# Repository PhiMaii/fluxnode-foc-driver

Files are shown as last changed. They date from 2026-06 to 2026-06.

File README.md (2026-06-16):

# FluxNode-FOC

FluxNode-FOC is a compact, general-purpose BLDC motor controller designed for field-oriented control in robotics, actuators, experimental drives, and motor-integrated applications.

The project combines a high-performance STM32G4 microcontroller, a three-phase MOSFET power stage, three-phase current sensing, rotor position sensing, phase-voltage measurement, CAN-FD communication, USB, temperature monitoring, and an optional brake chopper.

The design is intended to be understandable, repairable, and extensible rather than optimized only for minimum cost or minimum PCB area.

> **Project status:** Hardware and firmware architecture are still under development. Electrical values, component selections, interfaces, and PCB details may change before the first validated hardware revision.

---

## 1. Main design targets

| Parameter | Target |
|---|---:|
| Battery voltage | Up to 8S Li-ion/LiPo |
| Maximum normal battery voltage | 33.6 V |
| Design measurement range | Up to approximately 40 V |
| Nominal development voltage | 24 V |
| Continuous phase current target | Approximately 8 A RMS |
| Peak current target | Approximately 20 A |
| PWM frequency | 25 kHz |
| Control method | Field-oriented control |
| Power MOSFET voltage rating | 60 V |
| Bulk capacitor voltage rating | 50–63 V |
| Main communication interface | CAN-FD |
| MCU | STM32G474RE |
| Gate driver | DRV8323SRTAR |
| Main rotor encoder | AS5047P |
| PCB stackup | 6 layers preferred |

The controller is designed around **8S operation**, not 10S. A fully charged 8S battery reaches 33.6 V. Additional margin is required for wiring inductance, regenerative braking, switching transients, and load-disconnect events.

The system may be operated from lower voltages, including a 24 V laboratory supply, as long as the supply is compatible with regenerative energy or appropriate braking and overvoltage protection are provided.

---

## 2. Design philosophy

The main design priorities are:

1. Reliable and accurately timed current measurement for FOC.
2. Low-inductance power-stage layout.
3. Sufficient voltage margin for an 8S battery system.
4. Good observability through current, voltage, temperature, and diagnostic measurements.
5. Expandability for different motors, sensors, and actuator configurations.
6. Firmware that is understandable and not tightly coupled to a single framework.
7. Practical assembly and debugging with commonly available tools.

The design intentionally includes features that are not strictly required for basic FOC, such as phase-voltage sensing, several temperature channels, CAN-FD, an auxiliary sensor interface, and an optional brake chopper. These features make the controller more useful as a development platform and provide additional diagnostic and protection options.

---

## 3. System architecture

The controller is divided into the following main functional blocks:

- Power input and protection
- Auxiliary power supplies
- STM32G474 control section
- DRV8323 gate driver
- Three-phase MOSFET bridge
- Three-phase current measurement
- Phase-voltage and DC-bus voltage measurement
- Rotor-position sensing
- Temperature monitoring
- CAN-FD and USB communication
- Optional external sensor interfaces
- Optional brake chopper
- Fan and debug outputs

The KiCad schematic should remain split into logical hierarchical sheets rather than placing the entire design on one sheet.

Suggested schematic sheets:

```text
Power Input
Power Supplies
MCU Core
Gate Driver
Power Stage
Current Sense
Voltage Sense
Encoders and Sensors
CAN and USB
Temperature and Fan
Brake Chopper
Debug and Expansion
```

---

## 4. Microcontroller

The selected MCU is the **STM32G474RE**, based on the STM32G4 family.

Reasons for selecting this MCU include:

- High-performance Cortex-M4 core
- Floating-point unit
- Advanced motor-control timers
- Multiple fast ADCs
- Internal operational amplifiers and comparators
- CORDIC and FMAC accelerators
- Multiple SPI peripherals
- FDCAN support
- USB device support
- DAC outputs
- Good support through STM32CubeMX and STM32Cube firmware packages

The STM32G474xB/xC/xE datasheet is the reference MCU datasheet for this project.

### Motor-control timer

TIM1 is reserved for the three-phase complementary PWM outputs.

The current pin allocation uses:

- TIM1 channel 2 and channel 2N
- TIM1 channel 3 and channel 3N
- TIM1 channel 4 and channel 4N

TIM1 channel 4 on the selected STM32G474 package has a complementary output and can therefore be used as one of the three half-bridge PWM channels.

TIM1 should be configured for:

- Center-aligned PWM
- Complementary outputs
- Programmable dead time
- Break input support
- 25 kHz switching frequency
- ADC trigger generation at defined points in the PWM cycle

The exact output polarity and idle states must match the DRV8323 input configuration.

---

## 5. Gate driver

The selected gate driver is the **DRV8323SRTAR**.

It provides:

- Three half-bridge gate-drive channels
- SPI configuration and diagnostics
- Adjustable gate-drive strength
- Current-shunt amplifier support
- Fault reporting
- Undervoltage and overcurrent protection features

The gate driver is connected to the STM32 through:

- Six PWM signals
- SPI clock, COPI, CIPO, and chip select
- Enable signal
- nFAULT signal
- Optional additional diagnostic signals
- Analog VREF generated by an MCU DAC

### Gate-driver SPI

The gate driver shares SPI1 with the onboard magnetic encoder. Each device has a separate chip-select signal and is accessed sequentially.

This sharing is acceptable because neither device requires continuous full-bandwidth SPI traffic. Motor-control timing must not depend on slow or blocking SPI transactions.

The external auxiliary SPI connector uses SPI3 so that optional external hardware does not disturb the main gate-driver and encoder bus.

### nFAULT

The gate-driver fault output should be connected to an interrupt-capable GPIO input.

Software should log and decode the driver fault registers, but hardware protection must not rely only on software response time. Where practical, the timer break input should be used for immediate PWM shutdown.

### VREF

The DRV8323 current-sense amplifier reference is generated by a DAC output from the STM32 rather than being permanently tied to 3.3 V.

This allows the current-sense zero point to be adjusted in firmware. The DAC output must be properly decoupled and kept quiet because noise on VREF directly affects all current measurements.

---

## 6. Power stage

The three-phase inverter uses six external N-channel MOSFETs.

The currently selected phase MOSFET is:

- **TPW1R306PL**

The design uses 60 V MOSFETs to provide useful margin above the 33.6 V maximum battery voltage. This margin is still not sufficient by itself to tolerate uncontrolled regenerative voltage rise or poor PCB layout, so transient suppression and bus-voltage monitoring remain necessary.

### Power-stage layout priorities

The following loops must be kept as small as possible:

- High-side MOSFET, low-side MOSFET, and local ceramic/bulk capacitor commutation loop
- Gate-driver source and sink loops
- Bootstrap capacitor loops
- Current-shunt measurement loops

The gate driver and gate resistors must be placed close to the MOSFETs. Gate traces should be short, direct, and separated from high-current switching nodes.

Kelvin source connections should be used where practical for gate-drive return and current measurement.

The phase nodes are high-dV/dt switching nodes and should have limited copper area. They should not run beneath sensitive analog circuits, the encoder, the crystal, USB, or communication interfaces.

---

## 7. Power input and voltage protection

The input stage is designed for an 8S battery or a suitable DC supply.

Required or planned protection includes:

- Reverse-polarity protection where practical
- Input fuse or external fused supply
- TVS diode or equivalent transient suppression
- Local ceramic decoupling close to the bridge
- 50–63 V rated bulk capacitors
- DC-bus voltage measurement
- Firmware overvoltage and undervoltage limits
- Optional brake chopper
- Consideration of regenerative current into the source

The exact TVS voltage must be selected together with the maximum allowed bus voltage, MOSFET rating, gate-driver rating, and expected transient energy. It must not clamp during normal 8S operation but must act before the power stage is exposed to unsafe voltage.

A bench supply may not be able to absorb regenerative current. Motor deceleration can therefore raise the bus voltage even when the controller is powered from a regulated supply.

---

## 8. Current sensing

The design measures all three phase currents.

Each phase has its own shunt measurement path, allowing:

- Three-phase current reconstruction
- More flexible sampling
- Better diagnostics
- Detection of measurement inconsistencies
- Improved operation in modulation regions where two-shunt measurement becomes difficult

The phase-current channels are distributed across separate ADCs where possible so that they can be sampled simultaneously or with minimal timing skew.

The current measurements are configured as injected ADC conversions triggered by TIM1. Sampling should occur at a defined low-noise point in the PWM cycle.

Important requirements:

- Use differential/Kelvin routing from each shunt.
- Keep current-sense traces away from phase nodes and gate traces.
- Place input filtering near the receiving amplifier or ADC input as appropriate.
- Keep the three channels electrically symmetrical.
- Calibrate current offsets before enabling the power stage.
- Recheck offsets when temperature or VREF changes significantly.
- Detect ADC saturation and implausible current combinations.

Phase-current ADCs should remain the highest-priority analog measurements. Slower signals such as temperature and battery voltage should use regular conversions or lower-priority ADC resources.

---

## 9. Phase-voltage sensing

All three motor phases are measured through resistor dividers.

Phase-voltage sensing is not required for basic encoder-based FOC, but it provides several useful capabilities:

- Back-EMF observation
- Sensorless experimentation
- Motor-state diagnostics
- Phase-disconnection detection
- Verification of switching behavior
- Improved startup and fault analysis
- Potential observer development

The chosen divider concept uses two series high-side resistors and one low-side resistor to distribute voltage stress and improve routing.

The currently considered common value set is:

```text
High side: 2 × 51 kΩ
Low side: 6.8 kΩ
```

This ratio provides margin for phase and bus voltage excursions near 40 V while keeping the ADC voltage within the 3.3 V domain.

The final divider values must be verified against:

- ADC absolute maximum voltage
- Resistor tolerance
- Maximum expected transient voltage
- ADC input leakage
- Sampling-time requirements
- Desired measurement bandwidth

A small capacitor at the ADC-side divider node provides anti-aliasing and switching-noise filtering. A value around **1 nF** is currently considered for the phase-voltage channels, subject to final simulation and measurement.

The divider resistors should be placed close to the phase-sense pickup, while the final filter capacitor and any small series protection resistor should be placed close to the MCU ADC input. Routing between the divider and MCU must avoid switching nodes.

The phase voltages should be sampled from a timer-derived trigger at a repeatable point in the PWM cycle. They do not necessarily need the same timing priority as the phase currents.

---

## 10. DC-bus voltage sensing

The battery/DC-bus voltage is measured by an external resistor divider connected to an ADC channel.

The MCU VBAT pin is not used for measuring the motor supply. The external motor bus can reach approximately 40 V during transients and requires a dedicated divider.

The bus-voltage channel is used for:

- Undervoltage protection
- Overvoltage protection
- Brake-chopper control
- Regenerative-braking management
- Power and energy estimation
- Supply diagnostics

The same general divider ratio as the phase-voltage measurement may be used to simplify the bill of materials:

```text
High side: 2 × 51 kΩ
Low side: 6.8 kΩ
```

The bus voltage changes much more slowly than the phase-node voltage, so it should use stronger filtering than the phase-voltage channels. The final capacitor value should be chosen based on the desired brake-chopper response and ADC sampling rate.

The divider must be connected directly to the actual power-stage DC bus rather than to a remote or lightly loaded supply node.

---

## 11. Rotor-position sensing

The main onboard rotor encoder is the **AS5047P**.

It is connected by SPI and is intended to provide the rotor angle used by the FOC algorithm.

Reasons for choosing the AS5047P include:

- 14-bit absolute angle output
- High-speed SPI interface
- Suitability for motor-control applications
- On-chip dynamic angle error compensation
- Diagnostic information
- Common use in compact BLDC actuators

The encoder shares SPI1 with the DRV8323, using a separate chip-select signal.

Encoder transactions should be:

- Short
- Deterministic
- Checked for communication and parity errors
- Scheduled so they do not interfere with the current-control interrupt

DMA may be added later if it measurably improves timing or CPU load, but it is not required for initial firmware bring-up.

The PCB must respect the encoder manufacturer's magnet alignment, air-gap, magnetic-field, and keepout recommendations.

An additional external sensor interface is available through SPI3. This may be used for:

- A second encoder
- An off-axis sensor
- An external actuator sensor
- Experimental sensors

The external sensor is optional and not required for initial operation.

---

## 12. ADC allocation philosophy

The STM32G474 provides multiple ADCs, which are used to separate timing-critical and slow measurements.

The allocation philosophy is:

- Distribute the three phase-current measurements across ADC1, ADC2, and ADC3 where possible.
- Use injected conversions triggered by TIM1 for phase currents.
- Place phase-voltage measurements on available ADC channels, even when one ADC must contain two phase-voltage channels.
- Use regular conversions for bus voltage and temperature measurements.
- Use ADC4 and ADC5 for lower-priority auxiliary measurements where convenient.
- Avoid sacrificing correct phase-current timing merely to make the ADC channel allocation look symmetrical.

Current and phase-voltage measurements may share an ADC if the injected and regular sequences are configured carefully. The timing-critical current conversion always has priority.

---

## 13. Temperature monitoring

Planned temperature measurements include:

- Power MOSFET temperature
- Motor temperature
- Brake-chopper resistor or chopper-stage temperature
- MCU internal temperature

External temperatures are measured with NTC resistor dividers connected to ADC inputs.

Temperature monitoring is used for:

- Warning thresholds
- Current derating
- Fan control
- Controlled shutdown
- Fault logging

The MCU internal temperature sensor can be sampled in addition to the external channels. It is useful for board-level thermal monitoring but does not replace a sensor close to the MOSFETs.

NTC channels are slow signals and do not require timer-synchronous sampling.

---

## 14. Brake chopper

An optional brake chopper is included to prevent excessive DC-bus voltage during regenerative braking.

The brake chopper consists of:

- A power MOSFET
- Gate-drive circuitry
- An external or onboard braking resistor connection
- Bus-voltage feedback
- Temperature monitoring where practical
- Firmware control and fault limits

The braking resistor may be implemented as an external add-on connected through a dedicated power connector. This avoids placing a large, hot resistor on the compact controller PCB.

The chopper is controlled from a timer PWM output. It is currently assigned separately from the fan PWM so that both functions can operate independently.

The chopper is activated based on the measured DC-bus voltage. Typical firmware behavior will include:

1. Chopper remains off below the activation threshold.
2. PWM duty increases when the bus exceeds the target voltage.
3. Duty is reduced as the bus voltage falls.
4. A higher emergency threshold disables motor PWM if the chopper cannot control the bus.
5. Temperature and maximum duty limits protect the MOSFET and resistor.

The exact voltage thresholds depend on the final TVS selection, capacitor rating, MOSFET margin, and maximum permitted bus voltage.

The brake chopper must default to off during reset and startup.

---

## 15. Communication interfaces

### CAN-FD

CAN-FD is the main external real-time communication interface.

It is intended for:

- Commands and setpoints
- Telemetry
- Fault reporting
- Parameter configuration
- Multi-axis systems
- Daisy-chain-style wiring between actuator nodes

Electrical CAN wiring is a bus, not a logical point-to-point daisy chain. Connectors may provide CAN in and CAN out for convenient physical chaining, but all nodes share the same differential bus.

The controller should include:

- CAN transceiver
- CANH and CANL routing as a differential pair
- Optional switchable termination
- ESD protection near the connector
- Ground reference
- Suitable connector pinout for repeated nodes

Termination should only be enabled at the two physical ends of the CAN bus.

### USB-C

USB-C provides a local interface for:

- Firmware development
- Configuration
- Diagnostics
- Bootloader or device firmware update
- High-rate local telemetry where useful

USB is not intended to power the motor stage.

The USB section includes:

- USB 2.0 full-speed D+ and D−
- 22 Ω series resistors close to the MCU
- ESD protection close to the connector
- Correct USB-C CC resistors for a device
- VBUS sensing
- Protection against unwanted back-powering when USB and the motor battery are connected simultaneously

USB 5 V and the board's main supply must not be directly tied together without a deliberate power-path design.

---

## 16. Auxiliary interfaces

The board includes optional external interfaces for future sensors and accessories.

Planned interfaces include:

- SPI3 auxiliary sensor port
- I2C sensor port
- Fan connector
- External brake-resistor connector
- SWD debugging connector
- Debug LEDs
- Optional spare GPIO or timer signals where routing permits

The external SPI port is separate from the main SPI1 bus. This prevents an optional cable-connected device from adding excessive capacitance or noise to the gate-driver and onboard-encoder interface.

I2C is intended for relatively slow optional sensors. Pull-up resistors should be configurable or removable so that multiple boards or sensor modules do not unintentionally place too many pull-ups in parallel.

---

## 17. Fan control

An external fan can be controlled through a timer PWM output.

The fan output is independent of the brake-chopper PWM.

Firmware may control fan speed based on:

- MOSFET temperature
- Motor current
- Board temperature
- Brake-chopper activity
- User configuration

The MCU pin must not directly drive a fan motor. A suitable transistor or MOSFET stage, flyback protection where required, and connector decoupling must be provided.

---

## 18. Debugging and programming

The primary programming and debugging interface is SWD.

Required signals include:

- SWDIO
- SWCLK
- NRST
- GND
- Target reference voltage
- Optional SWO

SWO should be routed if pin availability allows it, because it can provide low-overhead debug output and timing information.

Boot configuration and reset access should remain available during bring-up.

At least two debug LEDs are planned for basic status and fault indication.

---

## 19. PCB stackup and layout

A **6-layer PCB** is preferred.

Although a 4-layer design is technically possible, the small additional fabrication cost of six layers is justified by the complexity of the mixed-signal motor-control board.

A possible six-layer stackup is:

```text
L1: Components, short signals, power-stage copper
L2: Solid ground plane
L3: Power distribution
L4: Secondary power and slower signals
L5: Solid ground plane
L6: Signals and low-current components
```

The exact stackup must be selected from the PCB manufacturer's controlled stackup options.

### Reasons for using six layers

- Better uninterrupted ground references
- Easier separation of power and sensitive analog routing
- Improved return-current paths
- More practical routing around the LQFP MCU
- Better EMI performance
- Easier CAN, USB, SPI, and ADC routing
- Reduced need to split or perforate the main ground plane

### Ground strategy

The design should use a continuous ground system rather than creating isolated analog and digital ground islands.

Sensitive analog circuits should be separated by placement and return-current control, not by cutting the ground plane.

High-current power returns must not share narrow copper paths with:

- ADC reference returns
- Current-sense returns
- Encoder ground
- USB ground
- MCU decoupling returns

Use stitching vias around noisy power areas, board edges where appropriate, and layer transitions.

### Placement order

Recommended placement order:

1. MOSFET bridge and power connectors
2. DC-link capacitors
3. Gate driver and gate components
4. Current shunts and sense paths
5. MCU and decoupling
6. Encoder
7. Power supplies
8. CAN and USB
9. Auxiliary connectors
10. Debug and low-priority circuitry

The power-stage layout should be completed before general digital routing.

---

## 20. Component sizes and assembly

The board uses a mixture of 0402 and 0603 passives.

General preference:

- Use 0402 where density or very low parasitic inductance matters.
- Use 0603 for resistor dividers, manually reworked parts, and components exposed to higher voltage.
- Use appropriately larger packages for high-power, high-voltage, or high-capacitance components.
- Do not select 0402 only to reduce board area if it makes probing and rework unnecessarily difficult.

For voltage dividers connected to the motor bus or phase nodes, 0603 resistors are preferred. Splitting the high-side resistance between two components reduces the voltage across each resistor and improves layout flexibility.

The PCB is intended to be assembled with solder paste, hot plate or reflow, hot air, flux, and hand rework where necessary. 0402 assembly is possible but requires careful paste control and inspection.

---

## 21. Firmware workflow

The firmware is generated initially with **STM32CubeMX** and developed in **Visual Studio Code**.

PlatformIO is not used for this project.

The intended workflow is:

1. Configure pins, clocks, ADCs, timers, DMA, communication peripherals, and middleware in STM32CubeMX.
2. Generate the STM32 project and initialization code.
3. Open and develop the generated project in Visual Studio Code.
4. Keep application code outside generated sections where possible.
5. Regenerate from CubeMX without overwriting project logic.
6. Build and debug using the selected ARM GCC/CMake or STM32-compatible toolchain.

The firmware will initially use STM32 HAL and LL drivers where appropriate. Time-critical motor-control code may use LL access or direct register operations after the basic system is validated.

### Firmware language

CubeMX generates C initialization code. The main firmware may remain primarily C, with carefully introduced C++ modules if they offer a clear architectural benefit.

The project should not depend on CubeMX generating native C++ code. C-generated peripheral initialization can be called from C++ through a compatible interface.

### Real-time priorities

Highest-priority operations include:

- PWM update
- Current sampling
- Current-control loop
- Hardware fault response

Lower-priority operations include:

- Encoder communication
- CAN processing
- USB communication
- Temperature conversion
- Logging
- Configuration storage
- User-interface functions

Blocking operations must not be used inside the fast control interrupt.

FreeRTOS is not required for the initial motor-control implementation. It may be evaluated later if the communication and application layers become complex enough to justify it.

---

## 22. Suggested repository structure

The project uses a single repository containing hardware, firmware, documentation, and tools.

```text
FluxNode-FOC/
├── README.md
├── LICENSE
├── .gitignore
├── docs/
│   ├── architecture/
│   ├── calculations/
│   ├── bring-up/
│   ├── measurements/
│   └── images/
├── hardware/
│   ├── kicad/
│   │   ├── FluxNode-FOC.kicad_pro
│   │   ├── FluxNode-FOC.kicad_sch
│   │   ├── FluxNode-FOC.kicad_pcb
│   │   └── sheets/
│   ├── libraries/
│   │   ├── symbols/
│   │   ├── footprints/
│   │   └── 3dmodels/
│   ├── production/
│   │   ├── gerbers/
│   │   ├── bom/
│   │   ├── pick-and-place/
│   │   └── assembly/
│   └── datasheets/
├── firmware/
│   ├── cubemx/
│   ├── Core/
│   ├── Drivers/
│   ├── App/
│   ├── MotorControl/
│   ├── Communication/
│   ├── BSP/
│   ├── Tests/
│   └── tools/
├── mechanical/
│   ├── cad/
│   ├── drawings/
│   └── exports/
└── scripts/
```

A monorepo is preferred because hardware and firmware revisions are tightly coupled. A tag or release can therefore identify the exact PCB, schematic, firmware, configuration, and documentation that belong together.

Generated production files should be placed in clearly versioned release folders or attached to Git releases rather than continuously overwriting unversioned files.

Large vendor libraries should not be copied into the repository unless their license permits it and they are required for reproducible builds.

---

## 23. Naming and revision conventions

Suggested conventions:

- Repository: `FluxNode-FOC`
- Firmware modules: lowercase or project-standard snake_case
- PCB revision: `REV_A`, `REV_B`, and so on
- Firmware semantic version: `v0.1.0`, `v0.2.0`, and so on
- Hardware-specific firmware configuration: explicitly tied to a PCB revision
- Nets: descriptive uppercase names such as `VBUS`, `PHASE_A`, `ISENSE_A`, and `DRV_NFAULT`

Each manufactured PCB revision should have a visible revision marking on the silkscreen.

Firmware should check or store the expected hardware revision where practical.

---

## 24. Bring-up strategy

Initial bring-up should be performed in controlled stages.

### Stage 1: Unpowered checks

- Visual inspection
- Resistance checks between all power rails and ground
- Verify MOSFET orientation
- Verify gate-driver and MCU pin orientation
- Check for solder bridges
- Check shunt and divider values
- Confirm connector polarity

### Stage 2: Low-voltage control power

- Use a current-limited supply
- Verify all regulated rails
- Confirm MCU programming and SWD
- Check reset and clock operation
- Test debug LEDs
- Verify USB without motor power

### Stage 3: Gate driver without motor operation

- Read and write SPI registers
- Confirm nFAULT behavior
- Verify DAC-generated VREF
- Observe PWM outputs with the bridge disabled
- Verify dead time and complementary polarity

### Stage 4: Power-stage switching

- Use a low DC-bus voltage
- Use strict current limiting
- Test one half bridge at a time where practical
- Observe gate voltage, switch node, and ringing
- Verify bootstrap operation
- Tune gate resistors only after measurements

### Stage 5: Sensor validation

- Calibrate current offsets
- Inject known current where possible
- Verify bus and phase-voltage scaling
- Check all NTC channels
- Verify encoder direction, zero, and diagnostics

### Stage 6: First motor operation

- Use a small motor and low bus voltage
- Start with limited voltage and current commands
- Validate phase order
- Validate encoder direction and electrical offset
- Test open-loop rotation before closed-loop current control
- Keep overcurrent and overvoltage limits conservative

### Stage 7: Full-power validation

- Increase voltage and current gradually
- Measure MOSFET and gate-driver temperature
- Validate bus transients
- Test regenerative braking
- Validate brake-chopper behavior
- Perform sustained thermal tests

---

## 25. Safety

This project controls motors from battery voltages and currents capable of causing burns, fire, component explosion, mechanical injury, and battery damage.

Development precautions include:

- Use a current-limited power source during bring-up.
- Add an appropriate fuse.
- Keep a physical emergency disconnect accessible.
- Secure the motor mechanically.
- Do not touch the board while powered.
- Use differential or isolated probing techniques for switching-node measurements.
- Do not connect an oscilloscope ground clip to a non-ground switching node.
- Treat lithium batteries as high-energy sources.
- Verify braking behavior before high-speed operation.
- Test overvoltage protection before relying on regenerative braking.

The controller is an experimental design and is not certified for safety-critical use.

---

## 26. Open design decisions

The following items are not yet final and must be confirmed before release:

- Final CAN transceiver and connector pinout
- Final auxiliary power-supply topology
- Final TVS diode and overvoltage thresholds
- Exact current-shunt resistance and power rating
- Current-sense amplifier gain and filtering
- Final voltage-divider capacitor values
- Brake-chopper MOSFET, gate driver, resistor rating, and connector
- Final fan voltage and output stage
- Exact ADC channel allocation
- Final SPI clock rates
- DMA usage for encoder and communication peripherals
- USB device class
- Final board dimensions and mounting pattern
- Final six-layer manufacturer stackup
- Exact thermal limits and current-derating curve
- Production test-point set
- Bootloader and firmware-update strategy

These items should be moved out of this section once they are validated and formally adopted.

---

## 27. Documentation policy

Important design decisions should be documented in the repository rather than existing only in chat logs or schematic comments.

For every major decision, record:

- What was selected
- Why it was selected
- Alternatives considered
- Important calculations
- Validation measurements
- Any revision-specific limitations

Hardware calculations, oscilloscope captures, thermal tests, and bring-up notes should be stored under `docs/`.

Datasheets should either be linked from documentation or stored under `hardware/datasheets/` when redistribution is permitted.

---

## 28. License

A license has not yet been finalized.

Before publishing the repository, choose separate or compatible licenses for:

- Hardware design files
- Firmware
- Documentation

Common choices include CERN-OHL for hardware and MIT, BSD, GPL, or Apache-2.0 for firmware. The final choice should reflect whether commercial reuse and closed-source derivatives are intended to be allowed.

---

## 29. Current project summary

The current FluxNode-FOC concept is a 6-layer, STM32G474-based FOC motor controller for up to 8S operation. It uses a DRV8323 SPI gate driver, external 60 V MOSFETs, three phase-current measurements, three phase-voltage measurements, DC-bus sensing, an AS5047P rotor encoder, CAN-FD, USB-C, temperature monitoring, fan control, and an optional external-resistor brake chopper.

The firmware is generated with STM32CubeMX and developed in Visual Studio Code without PlatformIO.

The project remains under active development, and all high-power functionality must be validated experimentally before the design is considered complete.

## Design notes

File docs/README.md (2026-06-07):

# FluxNode-FOC

FluxNode-FOC is a compact, universal BLDC/FOC motor driver based on an STM32G4 microcontroller. The first hardware revision is intended as a robust development ESC for small to medium BLDC motors, with the 5010 350KV motor used only as an initial test motor.

## Project Goal

The goal is to design a reusable 3-phase FOC ESC that can drive different BLDC motors, not just one specific motor. The design should be suitable for experiments with:

- FOC torque control
- robot actuators
- gimbal-style and drone-style BLDC motors
- compact motor-mounted driver boards
- future daisy-chained power and data distribution

The first revision prioritizes robustness, debugability, and electrical flexibility over absolute minimum size.

## Target Electrical Specification

| Parameter | Target |
|---|---:|
| Nominal DC bus voltage | 24 V |
| Operating voltage range | 8-28 V DC |
| Initial supply source | Bench power supply |
| MOSFET voltage class | 60 V |
| Capacitor voltage rating | preferably 50 V on VBUS |
| Continuous phase current | approx. 5-8 A RMS |
| Peak phase current | approx. 15-20 A |
| PWM frequency | 25 kHz default |
| Optional PWM range | approx. 20-40 kHz |
| PWM mode | 6-PWM |
| Current sensing | 3x low-side shunt |
| Default shunt value | 3 mOhm |
| Optional shunt values | 2 mOhm / 3 mOhm / 5 mOhm |
| PCB stackup | 4-layer PCB recommended |

## Motor Compatibility

The ESC is not designed only for the 5010 350KV test motor. It should be usable with a wider range of small and medium 3-phase BLDC motors, as long as they stay within the voltage, current, and thermal limits of the board.

The 5010 350KV motor is the initial validation motor because it is physically suitable for a compact motor-backpack layout and useful for FOC actuator experiments.

## PWM Frequency

The default PWM frequency should be 25 kHz.

Reasoning:

- 25 kHz is above the typical audible range and should reduce motor whining.
- It is a good compromise between acoustic behavior and switching losses.
- Higher PWM frequencies such as 32 kHz or 40 kHz may be supported in firmware, but they increase MOSFET switching losses and thermal stress.

The hardware should therefore be designed with MOSFETs and a gate driver that can reasonably support 25-40 kHz operation.

## Power Stage

The power stage should use external N-channel MOSFETs driven by a 3-phase gate driver.

Target MOSFET characteristics:

- 60 V VDS rating
- low RDS(on), preferably below roughly 5 mOhm if practical
- moderate gate charge for efficient 25-40 kHz PWM operation
- thermally capable package, preferably 5x6 mm power package such as LFPAK56, PowerPAK SO-8, PDFN 5x6, or similar
- good availability from common distributors

The design should avoid choosing MOSFETs only by lowest RDS(on). Gate charge, switching losses, package thermals, and layout practicality are also important.

## Gate Driver

The preferred architecture is a 3-phase smart gate driver for external MOSFETs.

Required or strongly preferred features:

- support for 3-phase BLDC power stage
- support for 6-PWM control from the STM32
- suitable for a 24 V nominal / 60 V class design
- bootstrap high-side drive
- fault output to the MCU
- undervoltage lockout
- overcurrent or short-circuit protection
- compatibility with 3-shunt low-side current sensing
- operation at 25 kHz PWM, with margin for higher PWM frequencies

## Current Sensing

The ESC should use three low-side shunts, one per phase leg.

The shunts should be treated as configurable assembly options:

| Shunt value | Use case |
|---:|---|
| 5 mOhm | smaller motors, better current resolution |
| 3 mOhm | default universal value |
| 2 mOhm | higher current range, lower loss |

Recommended default:

- 3 mOhm
- 1% tolerance
- current-sense type resistor
- preferably Kelvin / 4-terminal style
- 2512 or comparable high-power package
- at least 1 W, preferably 2 W depending on selected part

Sense routing should use Kelvin connections from each shunt to the current-sense amplifier or MCU analog front-end.

Suggested signal names:

```text
R_SHUNT_U
R_SHUNT_V
R_SHUNT_W

ISENSE_U_P
ISENSE_U_N
ISENSE_V_P
ISENSE_V_N
ISENSE_W_P
ISENSE_W_N
```

## Brake Chopper Option

The PCB should include an optional brake chopper circuit as a DNP / optional assembly feature.

A brake chopper protects the DC bus when the motor regenerates energy during braking or external motion. This is especially important when using a bench power supply, because many bench supplies cannot absorb reverse current. In that case, regenerated energy can raise VBUS and damage the MOSFETs, capacitors, gate driver, regulator, or other parts.

The brake chopper should dump excess energy into an external braking resistor when VBUS rises above a firmware-defined threshold.

Preferred topology:

```text
VBUS+ ---- external braking resistor ---- BRK-
                                             |
                                      Drain Q_BRK
                                      Source Q_BRK
                                             |
                                            GND
```

When the brake MOSFET turns on, current flows:

```text
VBUS+ -> braking resistor -> brake MOSFET -> GND
```

Recommended implementation:

- low-side N-MOSFET brake switch
- external braking resistor connector
- gate driven by STM32 GPIO or PWM output
- gate resistor, e.g. 10-47 ohm
- gate pulldown, e.g. 100 kOhm
- VBUS measurement through ADC
- optional hardware comparator in a later revision
- TVS diode on VBUS still required for fast transients

Suggested signal and part names:

```text
VBUS_SENSE
BRAKE_GATE
BRK+
BRK-

Q_BRK
R_BRK_G
R_BRK_PD
J_BRK
D_TVS
```

The braking resistor does not need to be placed on the PCB. A connector for an external resistor is preferred because braking resistors can dissipate significant heat.

Example braking resistor values for testing at approximately 30 V bus voltage:

| Resistor | Current | Power |
|---:|---:|---:|
| 100 ohm | 0.3 A | 9 W |
| 47 ohm | 0.64 A | 19 W |
| 22 ohm | 1.36 A | 41 W |
| 10 ohm | 3 A | 90 W |

For early tests, an external resistor around 47-100 ohm with sufficient power rating can be used.

## Protection Features

The design should include or reserve support for:

- gate driver fault signal to MCU
- VBUS voltage measurement
- undervoltage handling in firmware
- overvoltage detection in firmware
- overcurrent protection
- TVS diode across VBUS and GND
- NTC temperature sensor near the MOSFETs
- sufficient VBUS bulk capacitance close to the power stage
- careful startup current limiting in firmware

The TVS diode is not a replacement for the brake chopper. The TVS handles short voltage spikes, while the brake chopper handles longer regenerative braking events.

## Bench Power Supply Testing Notes

Initial testing should be done conservatively:

1. Start at 12 V, not 24 V.
2. Use a low current limit, for example 1-2 A.
3. Test first without load.
4. Verify gate signals before enabling high current operation.
5. Verify current-sense readings before closed-loop FOC.
6. Increase voltage and current limits gradually.
7. Be careful with braking or externally spinning the motor, because the bench supply may not absorb regenerated energy.

## PCB Design Direction

The board should use a 4-layer stackup.

Recommended direction:

- Layer 1: signal and power components
- Layer 2: solid GND plane
- Layer 3: power distribution, VBUS, possibly additional GND areas
- Layer 4: signals and secondary routing

Layout priorities:

- compact MOSFET half-bridge layout
- short gate traces
- tight high-current loops
- low-inductance VBUS decoupling near MOSFETs
- Kelvin routing for shunts
- separation between noisy power stage and sensitive analog/current-sense signals
- large copper areas and thermal vias for MOSFET heat spreading
- NTC located close to the MOSFETs

## Current Design Decision Summary

The current baseline specification is:

> Universal 24 V class FOC ESC, 8-28 V input, 8 A RMS continuous phase current target, 20 A peak phase current target, 60 V MOSFETs, 25 kHz default PWM, 6-PWM control, three low-side configurable shunts, optional brake chopper, VBUS sensing, TVS protection, and MOSFET temperature sensing.

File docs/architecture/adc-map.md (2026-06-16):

# ADC Map

> Working draft. Use this document to record every analog channel, its timing class, scaling, calibration data, and validation evidence for the FluxNode-FOC hardware revision being documented.

| Field | Value |
|---|---|
| Project | FluxNode-FOC |
| Hardware revision | TBD |
| Firmware revision / commit | TBD |
| Source files | `README.md`, `firmware/flux-node-foc.ioc`, KiCad schematics |
| Status | Draft / fill in |
| Last reviewed | TBD |

## Scope

- In scope: ADC channel allocation, injected and regular conversion groups, trigger sources, sampling times, scaling equations, filtering, calibration constants, and validation measurements.
- Out of scope: Final protection thresholds and control-loop behavior, except where they depend directly on ADC measurements.

## Source Of Truth

| Item | Source | Notes |
|---|---|---|
| MCU ADC pin assignment | `firmware/flux-node-foc.ioc` | Update after CubeMX pin changes. |
| Signal names and routing | KiCad schematic sheets | Cross-check net names before release. |
| Measurement intent | `README.md` sections 8-13 | Current, phase voltage, bus voltage, and temperature philosophy. |

## Current ADC Allocation Summary

| ADC | Conversion type | Channel | MCU pin | Signal label | Measurement | Timing class | Notes |
|---|---|---:|---|---|---|---|---|
| ADC1 | Injected | 12 | PB1 | `DRV_SOB` | Phase current B | PWM synchronous | TBD |
| ADC2 | Injected | 12 | PB2 | `DRV_SOC` | Phase current C | PWM synchronous | TBD |
| ADC3 | Injected | 12 | PB0 | `DRV_SOA` | Phase current A | PWM synchronous | TBD |
| ADC1 | Regular | 2 | PA1 | `SENSE_U_B` | Phase voltage B | TBD | TBD |
| ADC2 | Regular | 1 | PA0 | `SENSE_U_C` | Phase voltage C | TBD | TBD |
| ADC2 | Regular | 9 | PC3 | `SENSE_U_A` | Phase voltage A | TBD | TBD |
| ADC3 | Regular | 5 | PB13 | `SENSE_VBAT` | DC bus voltage | Slow / protection | TBD |
| ADC4 | Regular | 3 | PB12 | `SENSE_TEMP_BRAKE` | Brake temperature | Slow | TBD |
| ADC4 | Regular | 5 | PB15 | `SENSE_USB_VBUS` | USB VBUS sense | Slow | TBD |
| ADC5 | Regular | 1 | PA8 | `SENSE_TEMP_FET` | MOSFET temperature | Slow | TBD |
| ADC5 | Regular | 2 | PA9 | `SENSE_TEMP_MOT` | Motor temperature | Slow | TBD |
| ADC5 | Regular | Internal | Internal | MCU temperature | MCU temperature | Slow | TBD |

## Injected Conversion Timing

| Item | Value | Notes / evidence |
|---|---|---|
| Trigger source | TIM1 TRGO2 | IOC currently uses `ADC_EXTERNALTRIGINJEC_T1_TRGO2`. |
| Trigger point | TBD | Define relative to center-aligned PWM carrier. |
| Sampling time | TBD | IOC currently uses 12.5 cycles for injected current channels. |
| Conversion order | TBD | Confirm generated code and simultaneous ADC behavior. |
| Offset handling | TBD | Define startup offset capture and runtime drift policy. |

## Regular Conversion Timing

| Measurement group | Channels | Rate target | Trigger / scheduling | Notes |
|---|---|---:|---|---|
| Phase voltage | TBD | TBD | TBD | Sample at repeatable PWM point if used for observers. |
| DC bus voltage | TBD | TBD | TBD | Must support overvoltage and brake-chopper decisions. |
| Temperatures | TBD | TBD | TBD | Slow signals; include filtering strategy. |
| USB VBUS | TBD | TBD | TBD | Define use in USB/power-path logic. |

## Scaling And Units

| Signal | Raw ADC unit | Engineering unit | Equation | Component values | Calibration constants |
|---|---|---|---|---|---|
| `DRV_SOA` | counts | A | TBD | shunt/gain TBD | TBD |
| `DRV_SOB` | counts | A | TBD | shunt/gain TBD | TBD |
| `DRV_SOC` | counts | A | TBD | shunt/gain TBD | TBD |
| `SENSE_U_A` | counts | V | TBD | divider/filter TBD | TBD |
| `SENSE_U_B` | counts | V | TBD | divider/filter TBD | TBD |
| `SENSE_U_C` | counts | V | TBD | divider/filter TBD | TBD |
| `SENSE_VBAT` | counts | V | TBD | divider/filter TBD | TBD |
| Temperature channels | counts | deg C | TBD | NTC network TBD | TBD |

## Filtering

- Hardware filters: TBD.
- Firmware filters: TBD.
- Latency budget for protection decisions: TBD.
- Noise/ripple acceptance criteria: TBD.

## Calibration Hooks

- Current-sense offset calibration: see `docs/calibration.md`.
- Voltage-divider gain calibration: see `docs/calibration.md`.
- Temperature calibration: see `docs/calibration.md`.

## Validation Checklist

- [ ] Confirm every ADC channel against KiCad net labels.
- [ ] Confirm CubeMX generated code matches this map.
- [ ] Measure ADC reference voltage.
- [ ] Verify current zero offsets with power stage disabled.
- [ ] Verify current scaling with a known current.
- [ ] Verify bus-voltage scaling at several known input voltages.
- [ ] Verify phase-voltage scaling with PWM disabled and enabled.
- [ ] Verify temperature readings against known temperatures.
- [ ] Record oscilloscope or logic-analyzer evidence for ADC trigger timing.

## Open Questions

- TBD: Final shunt value and current-sense amplifier gain.
- TBD: Final phase-voltage and bus-voltage divider capacitor values.
- TBD: Whether phase-voltage channels use timer-triggered regular conversions or software scheduling.
- TBD: DMA usage for regular ADC groups.

## Revision Notes

| Date | Change | Evidence |
|---|---|---|
| TBD | Initial fill-in | TBD |

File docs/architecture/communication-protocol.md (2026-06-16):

# Communication Protocol

> Working draft. Use this document to define the external command, telemetry, configuration, and fault protocol for FluxNode-FOC over CAN-FD and USB diagnostic links.

| Field | Value |
|---|---|
| Project | FluxNode-FOC |
| Hardware revision | TBD |
| Firmware revision / commit | TBD |
| Protocol version | TBD |
| Primary transport | CAN-FD |
| Secondary transport | USB CDC diagnostics / configuration |
| Status | Draft / fill in |
| Last reviewed | TBD |

## Scope

- In scope: CAN-FD identifiers, message layout, command semantics, telemetry messages, configuration access, fault reporting, versioning, and USB diagnostic mapping.
- Out of scope: Low-level FDCAN driver implementation details except when required to preserve timing, safety, or compatibility.

## Source Of Truth

| Item | Source | Notes |
|---|---|---|
| Communication intent | `README.md` section 15 | CAN-FD is the main external real-time interface. |
| FDCAN peripheral setup | `firmware/flux-node-foc.ioc` | Current IOC uses FDCAN2 with CAN-FD BRS enabled. |
| USB device class | `firmware/flux-node-foc.ioc` | Current IOC uses USB CDC FS. |

## Transport Summary

| Transport | Purpose | Current IOC / design note | Status |
|---|---|---|---|
| CAN-FD | Commands, setpoints, telemetry, faults, configuration | FDCAN2, nominal rate currently about 1 Mbit/s, FD with BRS enabled | TBD |
| USB CDC | Local configuration, diagnostics, firmware development | USB full-speed CDC product string `FluxNode FOC` | TBD |

## Node Identity

| Field | Size / type | Source | Notes |
|---|---|---|---|
| Node ID | TBD | TBD | Must be unique on a bus. |
| Hardware revision | TBD | TBD | Include in identity response. |
| Firmware version | TBD | Build metadata | Include commit if practical. |
| Serial number | TBD | TBD | Optional for early bring-up. |
| Motor profile ID | TBD | Calibration/config storage | TBD |

## CAN-FD Frame Layout

| Field | Bits / bytes | Description |
|---|---:|---|
| CAN identifier | TBD | Standard or extended ID policy. |
| DLC | TBD | Payload length. |
| Message type | TBD | Command, telemetry, config, fault, response. |
| Sequence / counter | TBD | Optional missed-frame detection. |
| Payload | TBD | Message-specific data. |
| Checksum | TBD | Usually not needed beyond CAN CRC unless payload requires one. |

## Identifier Allocation

| ID range / base | Direction | Message class | Priority | Notes |
|---|---|---|---|---|
| TBD | Host -> node | Control setpoints | Highest | Must be deterministic. |
| TBD | Node -> host | Fast telemetry | High | Current, voltage, state. |
| TBD | Node -> host | Faults/events | High | Should transmit immediately. |
| TBD | Host <-> node | Configuration | Medium | Rate-limited. |
| TBD | Node -> host | Slow telemetry | Low | Temperature, diagnostics. |
| TBD | Host <-> node | Bootloader/service | TBD | Define later if used. |

## Command Messages

| Command | Direction | Rate | Payload | Valid states | Safety behavior |
|---|---|---:|---|---|---|
| Enable | Host -> node | Event | TBD | TBD | TBD |
| Disable | Host -> node | Event | TBD | Any | Must shut down PWM safely. |
| Current setpoint | Host -> node | TBD | TBD | Run | Timeout must disable or hold safe state. |
| Velocity setpoint | Host -> node | TBD | TBD | TBD | TBD |
| Position setpoint | Host -> node | TBD | TBD | TBD | TBD |
| Clear fault | Host -> node | Event | TBD | Fault | Only if fault condition is gone. |

## Telemetry Messages

| Message | Direction | Rate | Payload fields | Notes |
|---|---|---:|---|---|
| Fast electrical telemetry | Node -> host | TBD | currents, bus voltage, PWM/state | Keep compact. |
| Encoder telemetry | Node -> host | TBD | angle, velocity, status | TBD |
| Temperature telemetry | Node -> host | TBD | FET, motor, brake, MCU | Slow. |
| Fault telemetry | Node -> host | Event + repeat TBD | fault code, raw driver status, state | Must be logged. |
| Identity | Node -> host | On request | versions, IDs | TBD |

## Configuration Access

| Parameter group | Access | Persistence | Notes |
|---|---|---|---|
| Limits | Read/write | TBD | Current, voltage, temperature limits. |
| Calibration | Read/write guarded | TBD | See `docs/calibration.md`. |
| CAN settings | Read/write guarded | TBD | Changing these can disconnect the node. |
| Motor profile | Read/write | TBD | TBD |
| Debug settings | Read/write | Volatile or persistent TBD | TBD |

## Fault And State Reporting

| Fault code | Source | Severity | Latching | Recovery |
|---|---|---|---|---|
| Gate-driver fault | DRV8323 / `DRV_nFAULT` | Critical | TBD | Decode SPI registers before clear. |
| Overcurrent | ADC / hardware | Critical | TBD | TBD |
| Bus overvoltage | ADC / brake logic | Critical | TBD | TBD |
| Bus undervoltage | ADC | TBD | TBD | TBD |
| Overtemperature | NTC/internal | TBD | TBD | TBD |
| Encoder fault | AS5047P/SPI | TBD | TBD | TBD |
| Command timeout | Protocol watchdog | Critical | TBD | Disable torque command. |

## Timing And Watchdogs

- Command timeout: TBD.
- Fast telemetry rate: TBD.
- Slow telemetry rate: TBD.
- Configuration rate limit: TBD.
- Fault repeat interval: TBD.
- Behavior on bus-off: TBD.

## USB CDC Diagnostic Mapping

| Function | Format | Notes |
|---|---|---|
| Console log | TBD | Do not block real-time control. |
| Command shell | TBD | Optional. |
| Binary diagnostics | TBD | Optional. |
| Firmware update | TBD | Define if USB bootloader is used. |

## Versioning And Compatibility

- Protocol version field: TBD.
- Backward compatibility policy: TBD.
- Unknown message behavior: TBD.
- Endianness: TBD.
- Numeric units and scaling: TBD.

## Test Cases

- [ ] Node identity request/response.
- [ ] Enable/disable sequence.
- [ ] Command timeout behavior.
- [ ] Fault message after forced `DRV_nFAULT`.
- [ ] Bus-off or disconnected CAN behavior.
- [ ] USB CDC enumeration and basic diagnostic exchange.
- [ ] High-rate telemetry does not disturb current-control timing.

## Open Questions

- TBD: Standard versus extended CAN identifiers.
- TBD: Binary payload schema and endianness.
- TBD: Whether USB uses the same protocol frames or a separate diagnostic shell.
- TBD: Bootloader and firmware-update strategy.

## Revision Notes

| Date | Change | Evidence |
|---|---|---|
| TBD | Initial fill-in | TBD |

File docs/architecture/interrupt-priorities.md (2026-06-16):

# Interrupt Priorities

> Working draft. Use this document to define the real-time interrupt policy for FluxNode-FOC, especially PWM/current-control timing, ADC completion, gate-driver faults, communication, and low-priority diagnostics.

| Field | Value |
|---|---|
| Project | FluxNode-FOC |
| Hardware revision | TBD |
| Firmware revision / commit | TBD |
| MCU | STM32G474RE |
| Priority grouping | `NVIC_PRIORITYGROUP_4` in current IOC |
| Status | Draft / fill in |
| Last reviewed | TBD |

## Scope

- In scope: NVIC priorities, preemption rules, ISR execution budget, interrupt ownership, deferred work, and fault-response policy.
- Out of scope: Full control-loop design, except where it determines interrupt timing or allowed work inside an ISR.

## Source Of Truth

| Item | Source | Notes |
|---|---|---|
| Configured NVIC entries | `firmware/flux-node-foc.ioc` | Update after CubeMX changes. |
| Real-time policy | `README.md` section 21 | PWM, current sampling, current loop, and hardware faults have highest priority. |
| Timer and ADC timing | `docs/timer-map.md`, `docs/adc-map.md` | Keep trigger assumptions aligned. |

## Priority Policy

- Hardware shutdown paths must not depend only on firmware latency.
- Fast control interrupts must never perform blocking SPI, CAN, USB, logging, or heap allocation.
- ISR work should be bounded, measured, and moved to deferred tasks where possible.
- Communication interrupts must not delay current sampling or PWM update work.
- Slow measurement processing should run outside the fast control path.

## Interrupt Map

| Interrupt / event | Source | Current IOC priority | Intended priority | Owner module | ISR budget | Deferred work |
|---|---|---:|---:|---|---:|---|
| TIM1 update / compare | TIM1 PWM/control loop | TBD | TBD | Motor control | TBD us | TBD |
| ADC injected conversion complete | ADC1/2/3 current samples | `0` currently in IOC for ADC1_2 | TBD | Motor control | TBD us | Current processing/control loop TBD |
| `DRV_nFAULT` | EXTI4 on PC4 | `0` currently in IOC | TBD | Fault manager | TBD us | SPI fault-register read outside hard fault path |
| FDCAN2 IT0 | CAN-FD | `0` currently in IOC | TBD | Communication | TBD us | Message decode / app dispatch |
| USB LP | USB CDC | `0` currently in IOC | TBD | Diagnostics | TBD us | Console/protocol handling |
| SysTick | System tick | `15` currently in IOC | TBD | System | TBD us | Scheduler/timebase |
| HardFault / system faults | Cortex-M | Fixed | Fixed | System | N/A | Fault log if possible |

## Real-Time Execution Budget

| Task | Frequency / trigger | Max duration | Measurement method | Notes |
|---|---:|---:|---|---|
| Current sampling ISR entry to data ready | 25 kHz PWM related | TBD | GPIO toggle / SWO / timer capture | TBD |
| Current-control computation | TBD | TBD | TBD | TBD |
| PWM register update | TBD | TBD | TBD | TBD |
| Fault input to PWM disabled | Event | TBD | Scope measurement | Prefer hardware break where practical. |
| CAN RX ISR | Event / bus rate | TBD | TBD | Should enqueue only. |
| USB ISR | Event | TBD | TBD | Lowest practical urgency. |

## Fault Response Paths

| Fault source | Hardware immediate action | ISR action | Deferred action | Recovery policy |
|---|---|---|---|---|
| Gate-driver `nFAULT` | TBD | Disable torque/PWM if not already disabled | Read DRV8323 registers | TBD |
| Timer break input | TBD | Record event | Decode source | TBD |
| ADC overcurrent | TBD | TBD | Fault log | TBD |
| Bus overvoltage | TBD | Brake/PWM policy TBD | Fault log | TBD |
| Encoder communication fault | None | TBD | Diagnostics and state transition | TBD |
| Command timeout | None | TBD | Fault or safe state | TBD |

## Deferred Work Queues

| Queue / mechanism | Producer ISR | Consumer | Max depth | Overflow behavior |
|---|---|---|---:|---|
| CAN RX queue | FDCAN2 | Protocol task/main loop | TBD | TBD |
| Fault event queue | EXTI / ADC / timer | Fault manager | TBD | TBD |
| Telemetry buffer | Control loop / slow loop | CAN/USB transport | TBD | Drop or overwrite TBD |
| Log buffer | Any allowed source | USB/SWO logger | TBD | Non-blocking required |

## Prohibited ISR Operations

- Blocking SPI transactions.
- Blocking USB or CAN writes.
- Dynamic allocation.
- Long formatted printing.
- Flash erase/write.
- Waiting for ADC, timer, or communication flags in a polling loop.

## Validation Checklist

- [ ] Confirm generated NVIC priorities after CubeMX regeneration.
- [ ] Measure control ISR duration at target PWM frequency.
- [ ] Measure fault input to PWM-disabled latency.
- [ ] Confirm CAN RX load cannot starve control loop.
- [ ] Confirm USB traffic cannot starve control loop.
- [ ] Record ISR timing evidence in `docs/measurements/` or linked location.

## Open Questions

- TBD: Exact TIM1 interrupt source used for control-loop execution.
- TBD: Whether ADC ISR or TIM1 ISR owns current-control computation.
- TBD: Whether timer break input is routed and enabled.
- TBD: Final priority numbers for communication versus diagnostics.

## Revision Notes

| Date | Change | Evidence |
|---|---|---|
| TBD | Initial fill-in | TBD |

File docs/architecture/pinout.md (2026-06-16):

# Pinout

> Working draft. Use this document as the human-readable MCU, connector, and test-point pinout for FluxNode-FOC. Keep it synchronized with CubeMX and the KiCad schematic before each hardware release.

| Field | Value |
|---|---|
| Project | FluxNode-FOC |
| Hardware revision | TBD |
| Firmware revision / commit | TBD |
| MCU | STM32G474RETx, LQFP64 |
| Source files | `firmware/flux-node-foc.ioc`, KiCad schematics |
| Status | Draft / fill in |
| Last reviewed | TBD |

## Scope

- In scope: MCU pin assignments, signal labels, peripheral functions, connector pinouts, debug pins, power pins, and board-level notes.
- Out of scope: Electrical design calculations and firmware driver details.

## Source Of Truth

| Item | Source | Notes |
|---|---|---|
| MCU alternate functions and labels | `firmware/flux-node-foc.ioc` | Current generated configuration. |
| Connector pin numbers | KiCad schematic and PCB | Must be filled from hardware design. |
| External interface policy | `README.md` sections 15-18 | CAN-FD, USB, auxiliary SPI/I2C, SWD, LEDs. |

## MCU Pin Map

| MCU pin | Signal label | Peripheral / function | Direction | Schematic sheet | Connector / test point | Notes |
|---|---|---|---|---|---|---|
| PA0 | `SENSE_U_C` | ADC2_IN1 | Analog in | TBD | TBD | Phase voltage C. |
| PA1 | `SENSE_U_B` | ADC1_IN2 | Analog in | TBD | TBD | Phase voltage B. |
| PA2 | `DRV_CAL` | GPIO output | Out | TBD | TBD | Gate-driver calibration control. |
| PA3 | `DRV_EN` | GPIO output | Out | TBD | TBD | Gate-driver enable. |
| PA4 | `SPI1_DRV_CS` | GPIO output | Out | TBD | TBD | DRV8323 chip select. |
| PA5 | `SPI1_SCK` | SPI1 SCK | Out | TBD | TBD | Shared DRV8323 / AS5047P SPI bus. |
| PA6 | `SPI1_MISO` | SPI1 MISO | In | TBD | TBD | Shared SPI bus. |
| PA7 | `SPI1_MOSI` | SPI1 MOSI | Out | TBD | TBD | Shared SPI bus. |
| PA8 | `SENSE_TEMP_FET` | ADC5_IN1 | Analog in | TBD | TBD | MOSFET temperature. |
| PA9 | `SENSE_TEMP_MOT` | ADC5_IN2 | Analog in | TBD | TBD | Motor temperature. |
| PA11 | USB_DM | USB FS | Bidirectional | TBD | USB-C | TBD |
| PA12 | USB_DP | USB FS | Bidirectional | TBD | USB-C | TBD |
| PA13 | SWDIO | SWD | Bidirectional | TBD | SWD | Debug/programming. |
| PA14 | SWCLK | SWD | In | TBD | SWD | Debug/programming. |
| PB0 | `DRV_SOA` | ADC3_IN12 | Analog in | TBD | TBD | Phase current A. |
| PB1 | `DRV_SOB` | ADC1_IN12 | Analog in | TBD | TBD | Phase current B. |
| PB2 | `DRV_SOC` | ADC2_IN12 | Analog in | TBD | TBD | Phase current C. |
| PB3 | SWO | Trace | Out | TBD | SWD | Optional debug trace. |
| PB4 | `LED_PWR` | GPIO output | Out | TBD | LED | TBD |
| PB5 | FDCAN2_RX | FDCAN2 | In | TBD | CAN | TBD |
| PB6 | FDCAN2_TX | FDCAN2 | Out | TBD | CAN | TBD |
| PB7 | I2C1_SDA | I2C1 | Bidirectional | TBD | Auxiliary | TBD |
| PB8 | I2C1_SCL / BOOT0 | I2C1 / boot | Out / boot | TBD | Auxiliary | Check boot strapping. |
| PB9 | `DRV_PWM_LA` | TIM1_CH3N | Out | TBD | Gate driver | Low-side phase A TBD. |
| PB11 | `EXT_FAN` | TIM2_CH4 | Out | TBD | Fan | PWM fan output. |
| PB12 | `SENSE_TEMP_BRAKE` | ADC4_IN3 | Analog in | TBD | TBD | Brake temperature. |
| PB13 | `SENSE_VBAT` | ADC3_IN5 | Analog in | TBD | TBD | DC bus voltage. |
| PB14 | `DRV_PWM_LB` | TIM1_CH2N | Out | TBD | Gate driver | Low-side phase B TBD. |
| PB15 | `SENSE_USB_VBUS` | ADC4_IN5 | Analog in | TBD | USB-C | USB VBUS sense. |
| PC0 | `DRV_PWM_HC` | TIM1_CH1 | Out | TBD | Gate driver | High-side phase C TBD. |
| PC1 | `DRV_PWM_HB` | TIM1_CH2 | Out | TBD | Gate driver | High-side phase B TBD. |
| PC2 | `PWM_DRV_HA` | TIM1_CH3 | Out | TBD | Gate driver | High-side phase A TBD. |
| PC3 | `SENSE_U_A` | ADC2_IN9 | Analog in | TBD | TBD | Phase voltage A. |
| PC4 | `DRV_nFAULT` | EXTI4 | In | TBD | Gate driver | Fault interrupt. |
| PC5 | `SPI1_MAG_CS` | GPIO output | Out | TBD | Encoder | AS5047P chip select. |
| PC9 | `BRAKE_PWM` | TIM3_CH4 | Out | TBD | Brake chopper | PWM output. |
| PC10 | SPI3_SCK | SPI3 | Out | TBD | Auxiliary SPI | TBD |
| PC11 | SPI3_MISO | SPI3 | In | TBD | Auxiliary SPI | TBD |
| PC12 | SPI3_MOSI | SPI3 | Out | TBD | Auxiliary SPI | TBD |
| PC13 | `DRV_PWM_LC` | TIM1_CH1N | Out | TBD | Gate driver | Low-side phase C TBD. |
| PC14 | `SPI1_AUX1_CS` | GPIO output | Out | TBD | TBD | Uses OSC32_IN pin. |
| PD2 | `LED_DBG` | GPIO output | Out | TBD | LED | Debug LED. |
| PF0 | OSC_IN | HSE | In | TBD | Crystal/oscillator | TBD |
| PF1 | OSC_OUT | HSE | Out | TBD | Crystal/oscillator | TBD |
| PG10 | NRST | Reset | In | TBD | SWD/reset | TBD |

## Power And Motor Connectors

| Connector | Pin | Signal | Direction | Voltage/current | Notes |
|---|---:|---|---|---|---|
| Battery input | TBD | `VBUS` / battery + | In | TBD | XT connector TBD. |
| Battery input | TBD | GND | In | TBD | TBD |
| Motor phase | TBD | Phase A | Out | TBD | TBD |
| Motor phase | TBD | Phase B | Out | TBD | TBD |
| Motor phase | TBD | Phase C | Out | TBD | TBD |
| Brake resistor | TBD | TBD | Out | TBD | Optional external resistor. |

## Communication And Debug Connectors

| Connector | Pin | Signal | Direction | Notes |
|---|---:|---|---|---|
| CAN | TBD | CANH | Bidirectional | Termination policy TBD. |
| CAN | TBD | CANL | Bidirectional | TBD |
| CAN | TBD | GND | Reference | TBD |
| USB-C | TBD | D+ | Bidirectional | USB FS. |
| USB-C | TBD | D- | Bidirectional | USB FS. |
| SWD | TBD | SWDIO | Bidirectional | Debug/programming. |
| SWD | TBD | SWCLK | In | Debug/programming. |
| SWD | TBD | NRST | In | Reset. |
| SWD | TBD | SWO | Out | Optional trace. |

## Auxiliary Interfaces

| Interface | Signal | MCU pin | Connector pin | Pull-up / termination | Notes |
|---|---|---|---:|---|---|
| SPI3 auxiliary | SCK | PC10 | TBD | TBD | External sensor bus. |
| SPI3 auxiliary | MISO | PC11 | TBD | TBD | TBD |
| SPI3 auxiliary | MOSI | PC12 | TBD | TBD | TBD |
| I2C1 auxiliary | SDA | PB7 | TBD | TBD | Pull-up policy TBD. |
| I2C1 auxiliary | SCL | PB8 | TBD | TBD | BOOT0 interaction to verify. |
| Fan | `EXT_FAN` | PB11 | TBD | TBD | Requires external driver stage. |

## Pin Review Checklist

- [ ] Every CubeMX label matches KiCad net name.
- [ ] Every connector pin number is filled from schematic.
- [ ] High-current and high-voltage connector ratings confirmed.
- [ ] SWD and reset accessible on assembled board.
- [ ] BOOT0 behavior checked with I2C1_SCL use.
- [ ] CAN termination option documented.
- [ ] USB-C CC and VBUS behavior documented.
- [ ] Gate-driver PWM polarity verified against DRV8323 mode.

## Open Questions

- TBD: Final connector part numbers and pin numbers.
- TBD: Final phase naming convention A/B/C versus U/V/W.
- TBD: Whether `SPI1_AUX1_CS` remains on PC14.
- TBD: Whether TIM1 phase/channel assignment should be renamed for clarity.

## Revision Notes

| Date | Change | Evidence |
|---|---|---|
| TBD | Initial fill-in | TBD |

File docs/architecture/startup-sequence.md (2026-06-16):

# Startup Sequence

> Working draft. Use this document to define the firmware startup, self-test, calibration, enable, fault, and shutdown state flow for FluxNode-FOC.

| Field | Value |
|---|---|
| Project | FluxNode-FOC |
| Hardware revision | TBD |
| Firmware revision / commit | TBD |
| State-machine version | TBD |
| Status | Draft / fill in |
| Last reviewed | TBD |

## Scope

- In scope: boot order, hardware defaults, peripheral initialization, self-tests, calibration gates, communication readiness, motor-enable sequence, fault transitions, and shutdown.
- Out of scope: Full FOC algorithm details and external host application behavior.

## Source Of Truth

| Item | Source | Notes |
|---|---|---|
| Firmware workflow and priorities | `README.md` section 21 | Generated CubeMX init plus application code. |
| Bring-up stages | `README.md` section 24 and `docs/bring-up-checklist.md` | Keep startup gates compatible with bench bring-up. |
| ADC, timer, interrupt maps | `docs/adc-map.md`, `docs/timer-map.md`, `docs/interrupt-priorities.md` | Startup must configure these consistently. |

## Boot Principles

- Power-stage outputs default safe.
- Brake chopper defaults off.
- Gate driver remains disabled until preconditions pass.
- Fault inputs and voltage measurements are available before torque can be enabled.
- Calibration required for current sensing before motor PWM is enabled.
- External commands cannot bypass safety gates.

## State Overview

| State | Purpose | Entry conditions | Exit conditions | Fault exits |
|---|---|---|---|---|
| Reset | Hardware reset and default pin states | Power-on, reset, watchdog | MCU starts firmware | Hardware fault TBD |
| Boot | Clock and basic runtime setup | Reset complete | System init complete | Clock/init fault |
| Safe IO | Force safe GPIO/PWM defaults | Boot | Outputs confirmed safe | GPIO init fault |
| Peripheral init | ADC, timers, SPI, CAN, USB, GPIO | Safe IO | Required peripherals ready | Init fault |
| Self-test | Validate essential hardware | Peripheral init | Self-tests pass | Self-test fault |
| Calibration | Current/voltage/encoder prep | Self-test pass | Required calibration valid | Calibration fault |
| Idle | Ready but torque disabled | Calibration pass | Enable command | Any monitored fault |
| Run | Motor control active | Enable command and limits OK | Disable command / fault | Any critical fault |
| Fault | Torque disabled, fault latched | Fault detected | Clear command and condition gone | Persistent fault |
| Shutdown | Controlled disable / reset prep | Disable/reset/power-down | Reset or idle | TBD |

## Detailed Startup Steps

### 1. Reset Defaults

- [ ] Confirm gate-driver enable pin default safe.
- [ ] Confirm PWM pins default safe.
- [ ] Confirm brake PWM default off.
- [ ] Confirm fan default behavior.
- [ ] Confirm chip-select pins default inactive.

### 2. Clock And Runtime

- [ ] Configure system clock.
- [ ] Configure SysTick or timebase.
- [ ] Enable fault handlers.
- [ ] Initialize minimal fault logging.

### 3. GPIO And Safety Inputs

- [ ] Configure `DRV_EN`.
- [ ] Configure `DRV_CAL`.
- [ ] Configure `DRV_nFAULT` interrupt input.
- [ ] Configure debug LEDs.
- [ ] Configure chip-select outputs.
- [ ] Read initial fault pin state.

### 4. Measurement Peripherals

- [ ] Initialize ADCs.
- [ ] Initialize ADC trigger timer source.
- [ ] Validate ADC reference / internal temperature if used.
- [ ] Start required regular conversions.
- [ ] Confirm bus voltage is within startup range.

### 5. Timer And PWM Setup

- [ ] Initialize TIM1 in center-aligned mode.
- [ ] Configure complementary outputs and dead time.
- [ ] Keep PWM outputs disabled until enable gate.
- [ ] Configure TIM1 TRGO2 for ADC timing.
- [ ] Initialize fan and brake timers.

### 6. Communication Peripherals

- [ ] Initialize SPI1 for DRV8323 and AS5047P.
- [ ] Initialize SPI3 auxiliary bus if used.
- [ ] Initialize FDCAN2.
- [ ] Initialize USB CDC.
- [ ] Publish identity/status when safe.

### 7. Gate Driver And Encoder Checks

- [ ] Read DRV8323 status registers.
- [ ] Configure DRV8323 registers.
- [ ] Verify `DRV_nFAULT` is inactive.
- [ ] Read AS5047P angle.
- [ ] Check encoder diagnostics.

### 8. Calibration Gate

- [ ] Run or load current offsets.
- [ ] Validate current readings near zero.
- [ ] Validate bus voltage scaling enough for protection.
- [ ] Load encoder offset and phase order.
- [ ] Mark calibration status.

### 9. Enable Sequence

1. TBD: Receive valid enable command.
2. TBD: Check supply voltage and temperature limits.
3. TBD: Check gate-driver and encoder status.
4. TBD: Enable gate driver.
5. TBD: Start PWM with zero torque / safe duty.
6. TBD: Enter run state after measurements are stable.

## Fault Transition Rules

| Fault | Detection source | Immediate action | Latch? | Clear condition |
|---|---|---|---|---|
| Gate-driver fault | `DRV_nFAULT`, SPI status | Disable PWM/torque | TBD | Fault pin inactive and registers reviewed |
| Overcurrent | ADC / hardware | Disable PWM/torque | TBD | TBD |
| Bus overvoltage | ADC | Brake/PWM policy TBD | TBD | Bus below threshold |
| Bus undervoltage | ADC | Disable torque | TBD | Bus above threshold |
| Overtemperature | ADC | Derate or disable | TBD | Temperature below threshold |
| Encoder fault | SPI/diagnostic | Disable closed-loop torque | TBD | Encoder valid |
| Command timeout | Protocol watchdog | Disable torque | TBD | Fresh valid command |

## Shutdown Sequence

- [ ] Command torque to zero.
- [ ] Disable PWM outputs.
- [ ] Disable gate driver when appropriate.
- [ ] Turn brake chopper off unless overvoltage logic requires otherwise.
- [ ] Stop high-rate telemetry or mark inactive.
- [ ] Store fault/calibration state if required.

## Validation Checklist

- [ ] Scope confirms PWM pins stay safe during reset and boot.
- [ ] Fault input before enable prevents gate-driver enable.
- [ ] Invalid calibration prevents run state.
- [ ] Command timeout exits run state.
- [ ] Disable command exits run state cleanly.
- [ ] Startup behavior is repeatable after power cycle and reset.

## Open Questions

- TBD: Exact persistent calibration validity checks.
- TBD: Whether USB/CAN can command enable before full diagnostics are ready.
- TBD: Gate-driver register configuration sequence.
- TBD: Final brake-chopper behavior during startup overvoltage.

## Revision Notes

| Date | Change | Evidence |
|---|---|---|
| TBD | Initial fill-in | TBD |

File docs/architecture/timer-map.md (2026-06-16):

# Timer Map

> Working draft. Use this document to record all STM32 timer assignments, PWM frequencies, trigger outputs, synchronization points, and validation measurements for FluxNode-FOC.

| Field | Value |
|---|---|
| Project | FluxNode-FOC |
| Hardware revision | TBD |
| Firmware revision / commit | TBD |
| MCU timer clock | 170 MHz in current IOC |
| Status | Draft / fill in |
| Last reviewed | TBD |

## Scope

- In scope: TIM1 motor PWM, ADC trigger generation, brake-chopper PWM, fan PWM, timer-derived interrupts, dead time, update timing, and measurement evidence.
- Out of scope: Full control-loop math, except where timing affects execution.

## Source Of Truth

| Item | Source | Notes |
|---|---|---|
| Timer peripheral setup | `firmware/flux-node-foc.ioc` | Update after CubeMX regeneration. |
| Motor-control target | `README.md` sections 1 and 4 | PWM target is 25 kHz. |
| ADC trigger relationship | `docs/adc-map.md` | Keep TIM1 TRGO2 and ADC injected timing aligned. |

## Timer Allocation Summary

| Timer | Channel | Signal | MCU pin | Purpose | Frequency / period | Notes |
|---|---|---|---|---|---:|---|
| TIM1 | CH1 | `DRV_PWM_HC` | PC0 | Motor PWM high-side phase C TBD | 25 kHz target | Complementary pair with CH1N. |
| TIM1 | CH1N | `DRV_PWM_LC` | PC13 | Motor PWM low-side phase C TBD | 25 kHz target | Verify phase naming. |
| TIM1 | CH2 | `DRV_PWM_HB` | PC1 | Motor PWM high-side phase B TBD | 25 kHz target | Complementary pair with CH2N. |
| TIM1 | CH2N | `DRV_PWM_LB` | PB14 | Motor PWM low-side phase B TBD | 25 kHz target | Verify polarity. |
| TIM1 | CH3 | `PWM_DRV_HA` | PC2 | Motor PWM high-side phase A TBD | 25 kHz target | Complementary pair with CH3N. |
| TIM1 | CH3N | `DRV_PWM_LA` | PB9 | Motor PWM low-side phase A TBD | 25 kHz target | Verify naming. |
| TIM1 | CH4 no output | Internal | N/A | ADC trigger compare | TBD | Current IOC uses OC4REF as TRGO2. |
| TIM2 | CH4 | `EXT_FAN` | PB11 | Fan PWM | TBD | IOC period currently 6799. |
| TIM3 | CH4 | `BRAKE_PWM` | PC9 | Brake-chopper PWM | TBD | IOC period currently 6799. |

## TIM1 Motor PWM

| Setting | Current IOC value | Intended value | Notes |
|---|---:|---:|---|
| Counter mode | Center-aligned 1 | TBD | Required for symmetric PWM sampling. |
| Timer clock | 170 MHz | TBD | Confirm generated clock tree. |
| Period | 3399 | TBD | Yields 25 kHz with center-aligned counting at 170 MHz. |
| Dead time | 34 | TBD | Convert to ns and validate at gate. |
| TRGO2 | OC4REF | TBD | Used for injected ADC trigger. |
| OC4 compare | 3299 | TBD | Define exact sample point. |
| PWM idle states | TBD | TBD | Must match DRV8323 input mode. |
| Break input | TBD | TBD | Prefer hardware shutdown where practical. |

## ADC Trigger Timing

| Trigger | Source | Target sample point | Measurement evidence |
|---|---|---|---|
| Injected phase currents | TIM1 TRGO2 / OC4REF | TBD | TBD |
| Phase voltage sampling | TBD | TBD | TBD |
| Bus voltage sampling | TBD | TBD | TBD |

## Fan PWM

| Setting | Value | Notes |
|---|---:|---|
| Timer/channel | TIM2_CH4 | `EXT_FAN` on PB11. |
| Timer clock | 170 MHz current IOC | TBD |
| Period | 6799 current IOC | Calculate final PWM frequency. |
| Duty range | TBD | Define electrical output stage expectations. |
| Default state | TBD | Fan off or fail-safe behavior. |

## Brake-Chopper PWM

| Setting | Value | Notes |
|---|---:|---|
| Timer/channel | TIM3_CH4 | `BRAKE_PWM` on PC9. |
| Timer clock | 170 MHz current IOC | TBD |
| Period | 6799 current IOC | Calculate final PWM frequency. |
| Activation threshold | TBD | See protection design. |
| Default state | Off | README requires brake chopper default off during reset/startup. |
| Maximum duty | TBD | Protect resistor and MOSFET. |

## Timer Interrupt Ownership

| Timer event | ISR owner | Priority | Work allowed in ISR | Notes |
|---|---|---:|---|---|
| TIM1 update / compare | Motor control TBD | TBD | TBD | Fast path only. |
| TIM1 break | Fault manager TBD | TBD | Disable/log fault | TBD |
| TIM2 update | Fan control TBD | TBD | Usually none | Use hardware PWM. |
| TIM3 update | Brake control TBD | TBD | Usually none | Duty updated by slower loop. |

## Validation Checklist

- [ ] Verify TIM1 PWM frequency at MCU pin.
- [ ] Verify complementary polarity at MCU pin.
- [ ] Verify dead time at gate-driver inputs or gates.
- [ ] Verify ADC trigger point relative to PWM waveform.
- [ ] Verify PWM outputs remain safe during reset and startup.
- [ ] Verify fan PWM frequency and duty range.
- [ ] Verify brake PWM frequency, polarity, and default-off behavior.

## Open Questions

- TBD: Final phase naming between TIM1 channels and board phase outputs.
- TBD: Final dead-time value after MOSFET/gate-driver measurement.
- TBD: Whether TIM1 break input is routed and configured.
- TBD: Final fan and brake PWM frequencies.

## Revision Notes

| Date | Change | Evidence |
|---|---|---|
| TBD | Initial fill-in | TBD |

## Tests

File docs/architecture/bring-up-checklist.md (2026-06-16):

# Bring-Up Checklist

> Working draft. Use this document as the controlled hardware and firmware bring-up record for each FluxNode-FOC board revision and assembled unit.

| Field | Value |
|---|---|
| Project | FluxNode-FOC |
| Hardware revision | TBD |
| Board serial / unit ID | TBD |
| Firmware revision / commit | TBD |
| Operator | TBD |
| Bench supply / limits | TBD |
| Status | Not started / in progress / passed / blocked |
| Last reviewed | TBD |

## Scope

- In scope: staged bench bring-up, safety setup, required equipment, measurements, pass/fail records, deviations, and release criteria for an assembled board.
- Out of scope: Detailed calibration math, communication protocol definitions, and control-loop implementation details except where they are required to pass a bring-up stage.

## Source Of Truth

| Item | Source | Notes |
|---|---|---|
| Bring-up stages | `README.md` section 24 | This checklist expands the staged strategy into a board-level record. |
| Pin, ADC, and timer mappings | `docs/pinout.md`, `docs/adc-map.md`, `docs/timer-map.md` | Use these when checking signals and measurements. |
| Hardware details | KiCad schematic and PCB | Fill connector, test-point, and measurement expectations from the current revision. |

## Safety Setup

- [ ] Current-limited supply configured.
- [ ] Fuse or current-limited source in series with motor supply.
- [ ] Emergency disconnect reachable.
- [ ] Motor mechanically secured.
- [ ] Scope probing plan reviewed for ground safety.
- [ ] Thermal camera or temperature probe available for powered tests.
- [ ] Fire-safe bench area prepared for high-power tests.

## Required Equipment

| Equipment | Model / settings | Purpose | Ready |
|---|---|---|---|
| Bench supply | TBD | Low-voltage and motor-bus power | [ ] |
| Multimeter | TBD | Resistance and voltage checks | [ ] |
| Oscilloscope | TBD | PWM, gate, phase, and bus measurements | [ ] |
| Differential probe | TBD | Switching-node measurements | [ ] |
| SWD probe | TBD | Programming and debug | [ ] |
| CAN-FD adapter | TBD | Communication validation | [ ] |
| USB cable | TBD | USB CDC validation | [ ] |
| Test motor | TBD | First rotation | [ ] |

## Stage 1: Unpowered Checks

- [ ] Visual inspection complete.
- [ ] Component orientation checked.
- [ ] MOSFET orientation checked.
- [ ] Gate driver orientation checked.
- [ ] MCU orientation checked.
- [ ] Connector polarity checked.
- [ ] Power rails resistance to ground recorded.
- [ ] Shunt values checked.
- [ ] Voltage-divider values checked.
- [ ] NTC networks checked.
- [ ] Solder bridges corrected.

| Measurement | Expected | Actual | Pass | Notes |
|---|---:|---:|---|---|
| Battery input to GND resistance | TBD | TBD | [ ] | TBD |
| 5 V rail to GND resistance | TBD | TBD | [ ] | TBD |
| 3.3 V rail to GND resistance | TBD | TBD | [ ] | TBD |
| Phase U to GND resistance | TBD | TBD | [ ] | TBD |
| Phase V to GND resistance | TBD | TBD | [ ] | TBD |
| Phase W to GND resistance | TBD | TBD | [ ] | TBD |

## Stage 2: Low-Voltage Control Power

- [ ] Power supply current limit set to TBD.
- [ ] 3.3 V rail measured.
- [ ] Other auxiliary rails measured.
- [ ] MCU reset behavior verified.
- [ ] HSE clock verified.
- [ ] SWD connection works.
- [ ] Firmware can be flashed.
- [ ] Debug LEDs can be controlled.
- [ ] USB enumerates without motor power, if intended.

## Stage 3: Gate Driver Without Motor Operation

- [ ] `DRV_EN` default state verified.
- [ ] `DRV_CAL` behavior verified.
- [ ] SPI communication with DRV8323 verified.
- [ ] Gate-driver fault registers read and logged.
- [ ] `DRV_nFAULT` interrupt behavior verified.
- [ ] DAC / VREF behavior verified, if applicable.
- [ ] TIM1 PWM observed with bridge disabled.
- [ ] Complementary output polarity verified.
- [ ] Dead time measured.

## Stage 4: Power-Stage Switching

- [ ] Low DC-bus voltage selected: TBD V.
- [ ] Strict current limit selected: TBD A.
- [ ] No motor connected for first switching tests, if applicable.
- [ ] Half-bridge switching tested one phase at a time.
- [ ] Gate voltage measured.
- [ ] Phase-node ringing measured.
- [ ] Bootstrap behavior verified.
- [ ] MOSFET temperature checked.
- [ ] Gate resistors reviewed after measurement.

## Stage 5: Sensor Validation

- [ ] Current offset calibration complete.
- [ ] Known-current test complete.
- [ ] Bus-voltage scaling verified.
- [ ] Phase-voltage scaling verified.
- [ ] FET temperature channel verified.
- [ ] Motor temperature channel verified.
- [ ] Brake temperature channel verified.
- [ ] AS5047P communication verified.
- [ ] Encoder direction verified.
- [ ] Encoder diagnostics checked.

## Stage 6: First Motor Operation

- [ ] Small test motor selected and mounted.
- [ ] Low voltage selected: TBD V.
- [ ] Conservative current limit selected: TBD A.
- [ ] Phase order test complete.
- [ ] Encoder electrical offset calibration complete.
- [ ] Open-loop rotation verified.
- [ ] Closed-loop current control enabled at low current.
- [ ] Fault shutdown tested.

## Stage 7: Higher-Power Validation

- [ ] Voltage increased gradually.
- [ ] Current increased gradually.
- [ ] Sustained thermal test completed.
- [ ] Bus transients measured.
- [ ] Regenerative braking tested.
- [ ] Brake chopper tested.
- [ ] CAN-FD command and telemetry tested under load.
- [ ] USB diagnostics tested under load.

## Issues And Deviations

| ID | Stage | Finding | Severity | Resolution | Linked evidence |
|---|---|---|---|---|---|
| TBD | TBD | TBD | TBD | TBD | TBD |

## Release Criteria

- [ ] All required bring-up stages passed or explicitly waived.
- [ ] Known deviations documented.
- [ ] Calibration data stored.
- [ ] Firmware revision tagged or recorded.
- [ ] Hardware revision and unit ID recorded.

## Revision Notes

| Date | Change | Evidence |
|---|---|---|
| TBD | Initial fill-in | TBD |

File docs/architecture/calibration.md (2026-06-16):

# Calibration

> Working draft. Use this document to define repeatable calibration procedures and storage format for FluxNode-FOC current, voltage, temperature, and rotor-position measurements.

| Field | Value |
|---|---|
| Project | FluxNode-FOC |
| Hardware revision | TBD |
| Firmware revision / commit | TBD |
| Calibration data format | TBD |
| Status | Draft / fill in |
| Last reviewed | TBD |

## Scope

- In scope: current offsets, current gain, voltage-divider gain, temperature conversion, encoder zero/electrical offset, phase order, and calibration persistence.
- Out of scope: Motor parameter identification, controller gain tuning, and production-line automation details unless they directly affect calibration data.

## Source Of Truth

| Item | Source | Notes |
|---|---|---|
| Analog channel map | `docs/adc-map.md` | Keep signal names consistent. |
| Startup usage | `docs/startup-sequence.md` | Define what must be calibrated before enabling PWM. |
| Hardware values | KiCad schematic / BOM | Fill exact shunt, divider, and NTC values. |

## Calibration Data Model

| Field | Unit | Type / range | Default | Required before run | Notes |
|---|---|---|---|---|---|
| Current offset A | ADC counts or A | TBD | TBD | Yes | Phase A / `DRV_SOA`. |
| Current offset B | ADC counts or A | TBD | TBD | Yes | Phase B / `DRV_SOB`. |
| Current offset C | ADC counts or A | TBD | TBD | Yes | Phase C / `DRV_SOC`. |
| Current gain A | A/count | TBD | TBD | TBD | Optional per-phase gain correction. |
| Current gain B | A/count | TBD | TBD | TBD | Optional per-phase gain correction. |
| Current gain C | A/count | TBD | TBD | TBD | Optional per-phase gain correction. |
| Bus-voltage gain | V/count | TBD | TBD | Yes | Used for protection. |
| Phase-voltage gains | V/count | TBD | TBD | TBD | One value per phase if needed. |
| Temperature coefficients | TBD | TBD | TBD | TBD | NTC conversion data. |
| Encoder zero | mechanical/electrical angle | TBD | TBD | Yes | Define convention. |
| Phase order | enum | TBD | TBD | Yes | Define motor wiring convention. |

## Current Offset Calibration

### Preconditions

- [ ] Motor phase outputs disabled.
- [ ] Gate driver disabled or high impedance as required.
- [ ] No commanded current.
- [ ] ADC reference and VREF stable.
- [ ] Board temperature recorded.

### Procedure

1. TBD: Configure ADC injected conversions.
2. TBD: Collect samples per phase.
3. TBD: Reject outliers or saturated samples.
4. TBD: Calculate mean offset for each phase.
5. TBD: Store offsets and timestamp.
6. TBD: Verify corrected current is near zero.

### Acceptance Criteria

| Check | Limit | Result |
|---|---:|---|
| Offset noise RMS | TBD | TBD |
| Corrected zero-current error | TBD | TBD |
| Phase-to-phase offset consistency | TBD | TBD |

## Current Gain Calibration

| Step | Description | Expected result | Evidence |
|---|---|---|---|
| 1 | Apply known current or use calibrated load. | TBD | TBD |
| 2 | Record ADC readings. | TBD | TBD |
| 3 | Calculate gain correction. | TBD | TBD |
| 4 | Verify corrected current. | TBD | TBD |

## Voltage Calibration

### DC Bus Voltage

- Divider values: TBD.
- ADC channel: see `docs/adc-map.md`.
- Test voltages: TBD.
- Fit method: TBD.

| Applied voltage | Raw ADC | Calculated voltage | Error | Pass |
|---:|---:|---:|---:|---|
| TBD | TBD | TBD | TBD | [ ] |

### Phase Voltages

- Divider values: TBD.
- Filter values: TBD.
- Test method with PWM disabled: TBD.
- Test method with PWM enabled: TBD.

## Temperature Calibration

| Channel | Sensor type | Divider values | Conversion equation | Validation points |
|---|---|---|---|---|
| FET temperature | TBD | TBD | TBD | TBD |
| Motor temperature | TBD | TBD | TBD | TBD |
| Brake temperature | TBD | TBD | TBD | TBD |
| MCU internal temperature | Internal | N/A | TBD | TBD |

## Encoder And Phase Calibration

### Encoder Communication Check

- [ ] SPI transaction format confirmed.
- [ ] AS5047P angle read confirmed.
- [ ] Diagnostics read and decoded.
- [ ] Parity/error handling confirmed.

### Electrical Offset

1. TBD: Lock rotor or command alignment current.
2. TBD: Read encoder angle.
3. TBD: Determine electrical offset.
4. TBD: Validate with low-current rotation.
5. TBD: Store offset with motor identity.

### Phase Order And Direction

| Test | Expected | Actual | Result |
|---|---|---|---|
| Open-loop positive angle command | TBD | TBD | TBD |
| Encoder angle direction | TBD | TBD | TBD |
| Corrected FOC direction | TBD | TBD | TBD |

## Persistence And Versioning

- Storage location: TBD.
- Data version field: TBD.
- CRC/checksum: TBD.
- Factory reset behavior: TBD.
- Per-board versus per-motor data separation: TBD.

## Recalibration Triggers

- [ ] New PCB assembly.
- [ ] Current-sense component replacement.
- [ ] Encoder or magnet moved.
- [ ] Motor changed.
- [ ] Firmware calibration format changed.
- [ ] Temperature drift exceeds TBD.
- [ ] Validation check fails during startup.

## Open Questions

- TBD: Where calibration data is stored in nonvolatile memory.
- TBD: Whether current gain is calibrated per board or derived from BOM values.
- TBD: How motor-specific calibration is associated with a controller.

## Revision Notes

| Date | Change | Evidence |
|---|---|---|
| TBD | Initial fill-in | TBD |

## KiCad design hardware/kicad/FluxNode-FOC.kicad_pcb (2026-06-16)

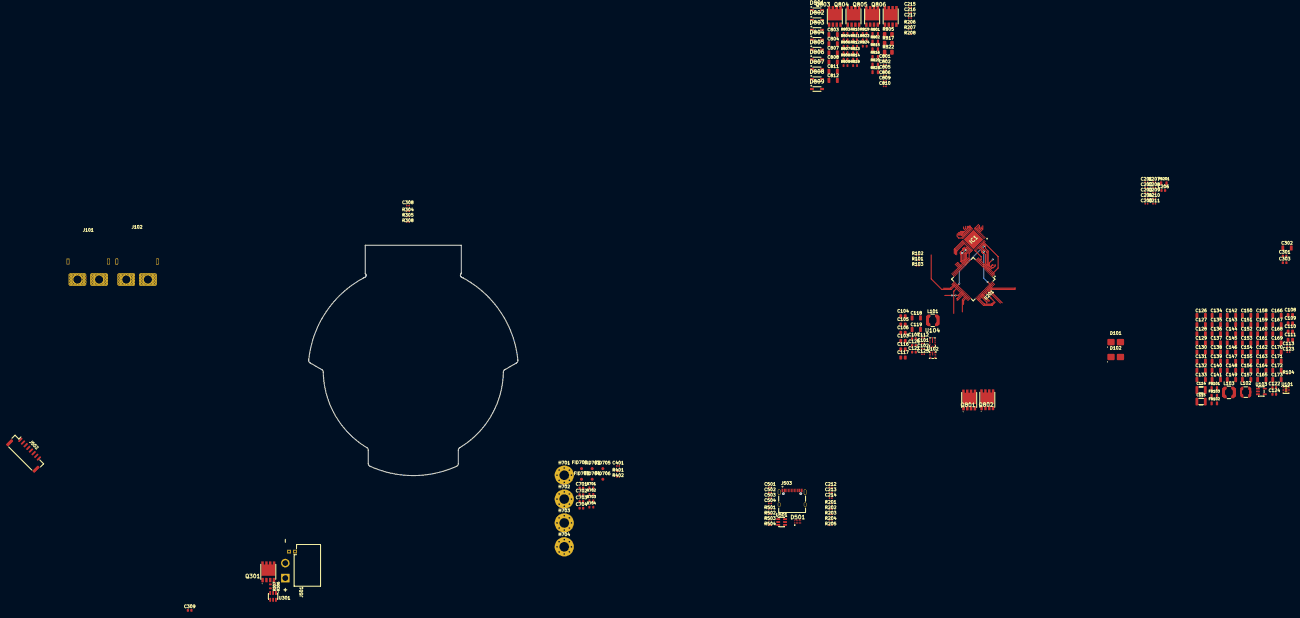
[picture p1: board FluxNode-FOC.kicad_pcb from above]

Board: 6 copper layers, 216 parts (0 on the bottom side), 93 nets.

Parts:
C101, C102, C113: 100nF X7R 50V; C_0402_1005_DensityHigh
C103, C111: 22uF X7R 10V; C_0805_2012_DensityHigh
C104, C116: 2u2 X7R 100V; C_0805_2012_DensityHigh
C105, C106, C108, C109, C117: 2u2 100V; C_0805_2012_DensityHigh
C107, C303: 100nF 100V; C_0603_1608_DensityHigh
C110: 10u 25V; C_0805_2012_DensityHigh
C112, C201, C209: 1uF X7R 10V; C_0402_1005_DensityHigh
C114, C115: 15uF 25V; C_1210_3225_DensityHigh
C118, C119, C302: 4u7 100V; C_1206_3216_DensityHigh
C120, C121: 220n 100V; C_0603_1608_DensityHigh
C122, C301: 1u 25V; C_0603_1608_DensityHigh
C123: 10n 100V; C_0402_1005_DensityHigh
C124, C206: 4.7u 16V; C_0603_1608_DensityHigh
C125: 1u X7R 10V; C_0402_1005_DensityHigh
C126, C127, C128, C129, C130, C131, C132, C133, C134, C135, C136, C137, C138, C139, C140, C141, C142, C143, C144, C145, C146, C147, C148, C149, C150, C151, C152, C153, C154, C155, C156, C157, C158, C159, C160, C161, C162, C163, C164, C165, C166, C167, C168, C169, C170, C171, C172, C173, C803, C808, C812: 4.7u 100V; C_1206_3216_DensityHigh
C202, C203, C204, C205, C208, C210, C401: 100n 50V; C_0402_1005_DensityHigh
C207: 1uF 10V; C_0402_1005_DensityHigh
C211: 4.7u X5R 25V; C_0402_1005_DensityHigh
C212, C213, C214: 1nF 25V; C_0402_1005_DensityHigh
C215, C216, C217: 470pF 50V; C_0402_1005_DensityHigh
C308, C503, C504: 100nF 50V; C_0402_1005_DensityHigh
C309: 1uF 50V; C_0603_1608_DensityHigh
C501, C502: 100nF; C_0402_1005_DensityHigh
C701, C702, C703, C704: 1nF 1kV; C_0603_1608_DensityHigh
C801, C802, C805, C806, C809, C810: 3n3 10% 100V; C_0402_1005_DensityHigh
C804, C807, C811: 100nF 100V; C_1206_3216_DensityHigh
D101, D102: SMBJ51CD-M3_H; DIOM4336X24N
D501: PESD4USB3U-TBSX; PESD4USB3UTBSX
D801, D802, D803, D804, D805, D806, D807, D808, D809: BAT41ZFILM; SOD3816X145N
FB101, FB102, FB103, FB201: 1k @ 100MHz; R_0805_2012_DensityHigh
FID701, FID702, FID703, FID704, FID705, FID706: Fiducial; Fiducial_1mm_Mask2mm
H701, H702, H703, H704: MountingHole_Pad; MountingHole_3.2mm_M3_Pad_Via
IC1: DRV8323SRTAR; QFN50P600X600X80-41N-D
J101: XT60PW-F; AMASS_XT60PW-F_1x02_P7.20mm_Horizontal
J102: XT60PW-M; AMASS_XT60PW-M_1x02_P7.20mm_Horizontal
J501: XT30PW_2_2_-M.G.B; AMASS_XT30PW_2_2_-M.G.B
J502: Conn_01x08_Pin; JST_GH_SM08B-GHS-TB_1x08-1MP_P1.25mm_Horizontal
J503: TYPE-C-31-M-12; HRO_TYPE-C-31-M-12
L101, L103: 22uH 830mA 360mOhms; L_Coilcraft_LPS4018
L102: 2.2uH 1,2A 100mOhms; L_Coilcraft_LPS3314
Q301, Q801, Q802, Q803, Q804, Q805, Q806: TPW1R306PL; SOP_ADVANCE
R101: 10k 1% 50V; R_0402_1005_DensityHigh
R102: 0R; R_0402_1005_DensityHigh
R103: 100k 1% 50V; R_0402_1005_DensityHigh
R104: 9.09k 1% 50V; R_0402_1005_DensityHigh
R201, R202, R203, R204, R205: 22R 1%; R_0402_1005_DensityHigh
R206, R207, R208: 1K 1%; R_0402_1005_DensityHigh
R304: 100; R_0402_1005_DensityHigh
R305: 10k; R_0402_1005_DensityHigh
R306: 4.7; R_0603_1608_DensityHigh
R307: 1.5; R_0603_1608_DensityHigh
R308: 47k; R_0402_1005_DensityHigh
R401: 100k 1%; R_0402_1005_DensityHigh
R402: 8k2 1%; R_0402_1005_DensityHigh
R501, R502: 5k1 1%; R_0402_1005_DensityHigh
R503, R504: 100k; R_0402_1005_DensityHigh
R701, R702, R703, R704: 0R; R_0603_1608_DensityHigh
R801, R802, R815, R816, R820, R821: 7.5 1% 0.5W; R_0805_2012_DensityHigh
R803, R804, R818, R819, R823, R824: 5R 1% 0.4W; R_0603_1608_DensityHigh
R805, R817, R822: 0.5m 1% 2W; R_1206_3216_DensityHigh
R806, R807, R809, R810, R812, R813: 43k 1% 75V; R_0603_1608_DensityHigh
R808, R811, R814: 6k8 1% 75V; R_0603_1608_DensityHigh
U101: TPS62172DSG; WSON-8-1EP_2x2mm_P0.5mm_EP0.9x1.6mm_ThermalVias
U102: LMR36506MSC5RPERQ1; LMR36503
U103: LP2992IM5-3.3/NOPB; SOT-23-5
U104: LMR36006FSCQ; LMR36006
U201: STM32G474RET6; LQFP-64_10x10mm_P0.5mm
U301: UCC27511ADBV; SOT-23-6
U501: USBLC6-2SC6; SOT-23-6

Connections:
+3V3: C111.1, C201.1, C202.1, C203.1, C204.1, C205.1, C206.1, C503.1, L102.2, U201.1 (VBAT), U201.16 (VDD), U201.32 (VDD), U201.48 (VDD), U201.64 (VDD)
+5V: C102.1, C103.1, C108.1, C122.1, FB102.1, L101.2, R101.1, U103.1 (VIN)
+12V: C114.1, C115.1, C308.1, C309.1, L103.2, U301.1 (V_{DD})
+A3V3: C124.1, C209.1, FB201.2, IC1.24 (VREF), U103.5 (VOUT)
+VBAT: C104.1, C116.1, C126.1, C127.1, C128.1, C129.1, C130.1, C131.1, C132.1, C133.1, C134.1, C135.1, C136.1, C137.1, C138.1, C139.1, C140.1, C141.1, C142.1, C143.1, C144.1, C145.1, C146.1, C147.1, C148.1, C149.1, C150.1, C151.1, C152.1, C153.1, C154.1, C155.1, C156.1, C157.1, C158.1, C159.1, C160.1, C161.1, C162.1, C163.1, C164.1, C165.1, C166.1, C167.1, C168.1, C169.1, C170.1, C171.1, C172.1, C173.1, C301.1, C302.1, C303.1, C803.1, C804.1, C807.1, C808.1, C811.1, C812.1, D101.2, D102.2, FB101.1, FB103.1, IC1.4 (VM), IC1.5 (VDRAIN), J101.2, J102.2, J501.P, Q801.5 (D), Q801.6 (D), Q801.7 (D), Q801.8 (D), Q803.5 (D), Q803.6 (D), Q803.7 (D), Q803.8 (D), Q805.5 (D), Q805.6 (D), Q805.7 (D), Q805.8 (D), R401.1, R803.2, R818.2, R823.2
/01 Power Generation/5V_VIN_3V3: C109.1, C110.1, FB102.2, U101.2 (VIN)
/01 Power Generation/ADJ_A3V3: C123.1, U103.4 (ADJ)
/01 Power Generation/BOOT_5V: C101.2, U102.6 (BOOT)
/01 Power Generation/BOOT_12V: C113.2, U104.4 (BOOT)
/01 Power Generation/FB_DIV_12V: R103.2, R104.1, U104.7 (FB)
/01 Power Generation/F_VIN_5V: C105.1, C106.1, C107.1, FB101.2, U102.3 (EN/UVLO), U102.4 (VIN)
/01 Power Generation/F_VIN_12V: C117.1, C118.1, C119.1, C120.1, C121.1, FB103.2, U104.2 (VIN), U104.9 (EN), U104.10 (VIN)
/01 Power Generation/PG_5V: R101.2, U101.3 (EN), U102.2 (PGOOD), U103.3 (ON/~OFF)
/01 Power Generation/SW_3V3: L102.1, U101.7 (SW)
/01 Power Generation/SW_5V: C101.1, L101.1, U102.5 (SW)
/01 Power Generation/SW_12V: C113.1, L103.1, U104.3 (NC), U104.12 (SW)
/02 MCU/BRAKE_CTRL: R304.2, U201.41 (PC9)
/02 MCU/DRV_CAL: IC1.31 (CAL), U201.14 (PA2)
/02 MCU/DRV_EN: IC1.30 (ENABLE), U201.17 (PA3)
/02 MCU/DRV_PWM_HA: IC1.34 (INHA), U201.10 (PC2)
/02 MCU/DRV_PWM_HB: IC1.36 (INHB), U201.9 (PC1)
/02 MCU/DRV_PWM_HC: IC1.38 (INHC), U201.8 (PC0)
/02 MCU/DRV_PWM_LA: IC1.35 (INLA), U201.62 (PB9)
/02 MCU/DRV_PWM_LB: IC1.37 (INLB), U201.36 (PB14)
/02 MCU/DRV_PWM_LC: IC1.39 (INLC), U201.2 (PC13)
/02 MCU/DRV_SOA_FILT: C212.1, R201.1, U201.24 (PB0)
/02 MCU/DRV_SOB_FILT: C213.1, R202.1, U201.25 (PB1)
/02 MCU/DRV_SOC_FILT: C214.1, R203.1, U201.26 (PB2)
/02 MCU/DRV_nFAULT: IC1.25 (NFAULT), U201.22 (PC4)
/02 MCU/F_A3V3: C207.1, C208.1, C210.1, C211.1, FB201.1, U201.28 (VREF+), U201.29 (VDDA)
/02 MCU/NRST: C504.1, D501.1 (K), D501.10 (K), U201.7 (PG10)
/02 MCU/SENSE_UA: C215.1, R206.1, U201.11 (PC3)
/02 MCU/SENSE_UB: C216.1, R207.1, U201.13 (PA1)
/02 MCU/SENSE_UC: C217.1, R208.1, U201.12 (PA0)
/02 MCU/SENSE_VBAT: C401.1, R401.2, R402.1, U201.35 (PB13)
/02 MCU/SOA: IC1.23 (SOA), R201.2
/02 MCU/SOB: IC1.22 (SOB), R202.2
/02 MCU/SOC: IC1.21 (SOC), R203.2
/02 MCU/SPI1_DRV_CS: IC1.29 (NSCS), U201.18 (PA4)
/02 MCU/SPI1_MISO: IC1.26 (SDO), U201.20 (PA6)
/02 MCU/SPI1_MOSI: IC1.27 (SDI), U201.21 (PA7)
/02 MCU/SPI1_SCK: IC1.28 (SCLK), U201.19 (PA5)
/02 MCU/SWCLK: D501.4 (K), D501.7 (K), U201.50 (PA14)
/02 MCU/SWDIO: D501.5 (K), D501.6 (K), U201.49 (PA13)
/02 MCU/SWO: D501.2 (K), D501.9 (K), U201.56 (PB3)
/02 MCU/USB_D+: R204.1, U201.46 (PA12), U501.6 (I/O1)
/02 MCU/USB_D-: R205.1, U201.45 (PA11), U501.4 (I/O2)
/02 MCU/USB_VBUS_SENSE: C501.1, R503.1, R504.2, U201.37 (PB15)
/03 Motor Control - Brake Chopper/BRAKE_GATE: Q301.4 (G), R306.1, R307.1, R308.2
/03 Motor Control - Brake Chopper/OUTH: R306.2, U301.2 (OUTH)
/03 Motor Control - Brake Chopper/OUTL: R307.2, U301.3 (OUTL)
/03 Motor Control - Gate Driver/03 Motor Control - Inverter/FET_GH_A: D803.2 (A), Q801.4 (G), R801.2
/03 Motor Control - Gate Driver/03 Motor Control - Inverter/FET_GH_B: D805.2 (A), Q803.4 (G), R815.2
/03 Motor Control - Gate Driver/03 Motor Control - Inverter/FET_GH_C: D808.2 (A), Q805.4 (G), R820.2
/03 Motor Control - Gate Driver/03 Motor Control - Inverter/FET_GL_A: D801.1 (K), D802.2 (A), Q802.4 (G), R802.2
/03 Motor Control - Gate Driver/03 Motor Control - Inverter/FET_GL_B: D804.1 (K), D806.2 (A), Q804.4 (G), R816.2
/03 Motor Control - Gate Driver/03 Motor Control - Inverter/FET_GL_C: D807.1 (K), D809.2 (A), Q806.4 (G), R821.2
/03 Motor Control - Gate Driver/03 Motor Control - Inverter/PHA: C801.2, C802.2, Q801.1 (S), Q801.2 (S), Q801.3 (S), Q802.5 (D), Q802.6 (D), Q802.7 (D), Q802.8 (D), R806.2
/03 Motor Control - Gate Driver/03 Motor Control - Inverter/PHB: C805.2, C806.2, Q803.1 (S), Q803.2 (S), Q803.3 (S), Q804.5 (D), Q804.6 (D), Q804.7 (D), Q804.8 (D), R809.2
/03 Motor Control - Gate Driver/03 Motor Control - Inverter/PHC: C809.2, C810.2, Q805.1 (S), Q805.2 (S), Q805.3 (S), Q806.5 (D), Q806.6 (D), Q806.7 (D), Q806.8 (D), R812.2
/03 Motor Control - Gate Driver/03 Motor Control - Inverter/SNUB_HA: C801.1, R803.1
/03 Motor Control - Gate Driver/03 Motor Control - Inverter/SNUB_HB: C805.1, R818.1
/03 Motor Control - Gate Driver/03 Motor Control - Inverter/SNUB_HC: C809.1, R823.1
/03 Motor Control - Gate Driver/03 Motor Control - Inverter/SNUB_LA: C802.1, R804.1
/03 Motor Control - Gate Driver/03 Motor Control - Inverter/SNUB_LB: C806.1, R819.1
/03 Motor Control - Gate Driver/03 Motor Control - Inverter/SNUB_LC: C810.1, R824.1
/03 Motor Control - Gate Driver/03 Motor Control - Inverter/SRC_LS_A: C804.2, Q802.1 (S), Q802.2 (S), Q802.3 (S), R804.2, R805.2
/03 Motor Control - Gate Driver/03 Motor Control - Inverter/SRC_LS_B: C807.2, Q804.1 (S), Q804.2 (S), Q804.3 (S), R817.2, R819.2
/03 Motor Control - Gate Driver/03 Motor Control - Inverter/SRC_LS_C: C811.2, Q806.1 (S), Q806.2 (S), Q806.3 (S), R822.2, R824.2
/03 Motor Control - Gate Driver/GHA: D803.1 (K), IC1.6 (GHA), R801.1
/03 Motor Control - Gate Driver/GHB: D805.1 (K), IC1.15 (GHB), R815.1
/03 Motor Control - Gate Driver/GHC: D808.1 (K), IC1.16 (GHC), R820.1
/03 Motor Control - Gate Driver/GLA: D802.1 (K), IC1.8 (GLA), R802.1
/03 Motor Control - Gate Driver/GLB: D806.1 (K), IC1.13 (GLB), R816.1
/03 Motor Control - Gate Driver/GLC: D809.1 (K), IC1.18 (GLC), R821.1
/03 Motor Control - Gate Driver/SENSE_UA: R807.1, R808.2
/03 Motor Control - Gate Driver/SENSE_UB: R810.1, R811.2
/03 Motor Control - Gate Driver/SENSE_UC: R813.1, R814.2
/05 Interface - Interconnects/D+: J503.A6 (DP1), J503.B6 (DP2), U501.1 (I/O1)
/05 Interface - Interconnects/D-: J503.A7 (DN1), J503.B7 (DN2), U501.3 (I/O2)
/05 Interface - Interconnects/USB_CC1: J503.A5 (CC1), R502.1
/05 Interface - Interconnects/USB_CC2: J503.B5 (CC2), R501.1
/BRAKE_SW: J501.N, Q301.5 (D), Q301.6 (D), Q301.7 (D), Q301.8 (D)
CHASSIS: C701.1, C702.1, C703.1, C704.1, D101.1, D102.1, H701.1 (1_1), H702.1 (1_1), H703.1 (1_1), H704.1 (1_1), J101.MP2, J102.MP2, J503.S1 (SHIELD), J503.S2 (SHIELD), J503.S3 (SHIELD), J503.S4 (SHIELD), R701.1, R702.1, R703.1, R704.1
GND: C102.2, C103.2, C104.2, C105.2, C106.2, C107.2, C108.2, C109.2, C110.2, C111.2, C112.2, C114.2, C115.2, C116.2, C117.2, C118.2, C119.2, C120.2, C121.2, C122.2, C123.2, C124.2, C125.2, C126.2, C127.2, C128.2, C129.2, C130.2, C131.2, C132.2, C133.2, C134.2, C135.2, C136.2, C137.2, C138.2, C139.2, C140.2, C141.2, C142.2, C143.2, C144.2, C145.2, C146.2, C147.2, C148.2, C149.2, C150.2, C151.2, C152.2, C153.2, C154.2, C155.2, C156.2, C157.2, C158.2, C159.2, C160.2, C161.2, C162.2, C163.2, C164.2, C165.2, C166.2, C167.2, C168.2, C169.2, C170.2, C171.2, C172.2, C173.2, C201.2, C202.2, C203.2, C204.2, C205.2, C206.2, C207.2, C208.2, C209.2, C210.2, C211.2, C212.2, C213.2, C214.2, C215.2, C216.2, C217.2, C302.2, C303.2, C308.2, C309.2, C401.2, C501.2, C503.2, C504.2, C701.2, C702.2, C703.2, C704.2, C803.2, C808.2, C812.2, D501.3 (A), D501.8 (A), D801.2 (A), D804.2 (A), D807.2 (A), IC1.32 (AGND), IC1.40 (PGND), IC1.41 (EP), J101.1, J102.1, J503.A1_B12 (GND), J503.B1_A12 (GND), Q301.1 (S), Q301.2 (S), Q301.3 (S), R102.2, R104.2, R305.1, R308.1, R402.2, R501.2, R502.2, R504.1, R701.2, R702.2, R703.2, R704.2, R805.1, R808.1, R811.1, R814.1, R817.1, R822.1, U101.1 (PGND), U101.4 (AGND), U101.5 (FB), U101.9 (PAD), U102.9 (GND), U103.2 (GND), U104.1 (PGND), U104.6 (AGND), U104.11 (PGND), U201.15 (VSS), U201.27 (VSSA), U201.31 (VSS), U201.47 (VSS), U201.63 (VSS), U301.4 (GND), U301.5 (IN-), U501.2 (GND)
unnamed: C301.2, IC1.3 (VCP)
unnamed: R806.1, R807.2
unnamed: R809.1, R810.2
unnamed: R812.1, R813.2
unnamed: C112.1, R102.1, U102.1 (MODE/SYNC)
unnamed: C125.1, U104.5 (VCC)
unnamed: R304.1, R305.2, U301.6 (IN+)
VBUS: C502.1, J503.A4_B9 (VBUS), J503.B4_A9 (VBUS), R503.2, U501.5 (VBUS)

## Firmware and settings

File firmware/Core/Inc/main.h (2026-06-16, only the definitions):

#define DRV_PWM_LC_Pin GPIO_PIN_13
#define DRV_PWM_LC_GPIO_Port GPIOC
#define SPI1_AUX1_CS_Pin GPIO_PIN_14
#define SPI1_AUX1_CS_GPIO_Port GPIOC
#define DRV_PWM_HC_Pin GPIO_PIN_0
#define DRV_PWM_HC_GPIO_Port GPIOC
#define DRV_PWM_HB_Pin GPIO_PIN_1
#define DRV_PWM_HB_GPIO_Port GPIOC
#define PWM_DRV_HA_Pin GPIO_PIN_2
#define PWM_DRV_HA_GPIO_Port GPIOC
#define SENSE_U_A_Pin GPIO_PIN_3
#define SENSE_U_A_GPIO_Port GPIOC
#define SENSE_U_C_Pin GPIO_PIN_0
#define SENSE_U_C_GPIO_Port GPIOA
#define SENSE_U_B_Pin GPIO_PIN_1
#define SENSE_U_B_GPIO_Port GPIOA
#define DRV_CAL_Pin GPIO_PIN_2
#define DRV_CAL_GPIO_Port GPIOA
#define DRV_EN_Pin GPIO_PIN_3
#define DRV_EN_GPIO_Port GPIOA
#define SPI1_DRV_CS_Pin GPIO_PIN_4
#define SPI1_DRV_CS_GPIO_Port GPIOA
#define DRV_nFAULT_Pin GPIO_PIN_4
#define DRV_nFAULT_GPIO_Port GPIOC
#define DRV_nFAULT_EXTI_IRQn EXTI4_IRQn
#define SPI1_MAG_CS_Pin GPIO_PIN_5
#define SPI1_MAG_CS_GPIO_Port GPIOC
#define DRV_SOA_Pin GPIO_PIN_0
#define DRV_SOA_GPIO_Port GPIOB
#define DRV_SOB_Pin GPIO_PIN_1
#define DRV_SOB_GPIO_Port GPIOB
#define DRV_SOC_Pin GPIO_PIN_2
#define DRV_SOC_GPIO_Port GPIOB
#define EXT_FAN_Pin GPIO_PIN_11
#define EXT_FAN_GPIO_Port GPIOB
#define SENSE_TEMP_BRAKE_Pin GPIO_PIN_12
#define SENSE_TEMP_BRAKE_GPIO_Port GPIOB
#define SENSE_VBAT_Pin GPIO_PIN_13
#define SENSE_VBAT_GPIO_Port GPIOB
#define DRV_PWM_LB_Pin GPIO_PIN_14
#define DRV_PWM_LB_GPIO_Port GPIOB
#define SENSE_USB_VBUS_Pin GPIO_PIN_15
#define SENSE_USB_VBUS_GPIO_Port GPIOB
#define BRAKE_PWM_Pin GPIO_PIN_9
#define BRAKE_PWM_GPIO_Port GPIOC
#define SENSE_TEMP_FET_Pin GPIO_PIN_8
#define SENSE_TEMP_FET_GPIO_Port GPIOA
#define SENSE_TEMP_MOT_Pin GPIO_PIN_9
#define SENSE_TEMP_MOT_GPIO_Port GPIOA
#define LED_DBG_Pin GPIO_PIN_2
#define LED_DBG_GPIO_Port GPIOD
#define LED_PWR_Pin GPIO_PIN_4
#define LED_PWR_GPIO_Port GPIOB
#define DRV_PWM_LA_Pin GPIO_PIN_9
#define DRV_PWM_LA_GPIO_Port GPIOB

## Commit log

2026-06-07 Moved PCB files into a seperate folder
    [FluxNode-FOC.kicad_pcb, FluxNode-FOC.kicad_sch]
2026-06-07 Added a README file with the current design goals
2026-06-07 Setup scematic hirarchy and different sheets
    [01_power.kicad_sch, 02-mcu.kicad_sch, 03_motor_driver.kicad_sch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]
2026-06-08 Added a firmware directory with the STM32 pinout config file
2026-06-08 Setup project structure with organised sub-sheets
    [01_power_connectors.kicad_sch, 01_power_generation.kicad_sch, 02-mcu.kicad_sch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]
2026-06-08 Added custom project footprint library
2026-06-11 Set up gate driver circuitry according to the datasheet
    [03_motor_control_gate_driver.kicad_sch]
2026-06-11 Added two XT-60 power connectors for daisy chaining multiple nodes together
    [01_power_connectors.kicad_sch]
2026-06-11 Power conditioning and generation of +3V3, +A3V3, +5V and +12V from VBat
    [01_power_generation.kicad_sch]
2026-06-11 Planned MCU pinout and wired it to the gate driver
    [02-mcu.kicad_sch]
2026-06-11 Updated project footprint and symbol library
2026-06-12 Added all missing pins and functionality to the MCU pinout
    [flux-node-foc.ioc]
2026-06-14 Added new symbols and related footprints
2026-06-14 Switched some sense pins for better ADC separation and utilisation
2026-06-14 Ported CubeMX pinout to KiCad; Setup all the main busses to communicate with peripherals
    [02-mcu.kicad_sch]
2026-06-14 Added a sheet for the brake chopper circuitry
    [03_motor_control_brake_chopper.kicad_sch]
2026-06-14 Added four mounting holes connected to chassis with decoupling to gnd and one single connection from chassis to gnd
    [07_misc.kicad_sch]
2026-06-14 Added USB and SWD ports with necessary circuitry and ESD protection
    [05_interface_interconnects.kicad_sch]
2026-06-14 Created blockout and connections of all the major parts
    [FluxNode-FOC.kicad_sch]
2026-06-14 Implemented brake chopper control with low side mosfet
    [03_motor_control_brake_chopper.kicad_sch]
2026-06-14 Added VBAT sensing via a voltage divider to stay within the MCU 3V3 limit
    [04_sensing_battery.kicad_sch]
2026-06-14 Added the XT-30 (2-2) connector for an external brake power resistor and a thermistor
    [05_interface_interconnects.kicad_sch]
2026-06-14 Added fiducials for the top and bottom PCB side
    [07_misc.kicad_sch]
2026-06-16 Updated pin configuration slightly and setup timers and adcs correctly
    [flux-node-foc.ioc]
2026-06-16 Unified all different LCSC part numbers of the same exact components to just one variant
    [01_power_connectors.kicad_sch, 01_power_generation.kicad_sch, 02-mcu.kicad_sch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]
2026-06-16 Unified naming sceme and made the minimum hole size 0.3mm accoriding to JLCPCB capabilities
2026-06-16 Updated silkscreen designators to a uniform stroke width of 0.15 mm and size of 0.8 by 0.8 mm
2026-06-16 Utilized new connector footprint
    [05_interface_interconnects.kicad_sch]
2026-06-16 Some minor changes to the annotations
    [01_power_connectors.kicad_sch, 01_power_generation.kicad_sch, FluxNode-FOC.kicad_pcb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]
2026-06-16 Reorganised pdb folder structure to acomodate seperate sheets folder and an erxternal lib folder
    [01_power_connectors.kicad_sch, 01_power_generation.kicad_sch, 02-mcu.kicad_sch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]

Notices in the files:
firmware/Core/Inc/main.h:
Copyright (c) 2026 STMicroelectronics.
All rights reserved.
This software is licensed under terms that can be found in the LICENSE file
